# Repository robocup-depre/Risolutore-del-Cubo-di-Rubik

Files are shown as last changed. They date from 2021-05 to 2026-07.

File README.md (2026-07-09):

# Rubik's Cube Solver

An automated, hardware-accelerated Rubik's Cube solver powered by a Python computer vision pipeline and an ATmega2560 microcontroller driving a 3D-printed, 6-axis stepper motor chassis. 

The machine interfaces directly with each face of the cube via a dedicated stepper motor attached to the center caps. It executes 180° rotations, as well as 90° clockwise and counterclockwise turns.

---

# Hardware Architecture & Electronics

The `Arduino/` folder contains the C++ firmware required for the microcontroller. While an Arduino Mega was used for this build, the footprint is small enough to run on an Arduino Uno as well. The system relies on **9 logical pins**:

* **Relay Control (1 Pin):** Engages or disengages the main 12V battery line. This isolates the stepper drivers when idling to eliminate motor humming and vibration.
* **Direction Line - DIR (1 Pin):** Sets the rotational direction (clockwise/counterclockwise). This line is shared globally across all stepper drivers.
* **Step Line - STEP (1 Pin):** Sends the pulse train to drive the motor steps. This line is also shared globally.
* **Enable Lines - EN1 to EN6 (6 Pins):** Individual driver enables. Because `STEP` and `DIR` are wired in parallel to all six drivers, the firmware pulls only one `EN` line low at any given instant to ensure that exactly one target motor executes the move.

The firmware listens continuously to the serial bus for instruction sets sent by the PC. Upon receiving a move command, it instantly pulses the active motor and relays an execution feedback signal back to the Python script.

> [!IMPORTANT]
> Before flashing the firmware, review the pin configuration constants at the top of the sketch file and adjust them to match your physical hardware mapping.

---

# Software & Computer Vision Pipeline

The `Python/` directory contains four modular scripts. The execution pipeline is handled through `main.py`, which initializes a Graphical User Interface (GUI) via `tkinter`.

### 1. Optical Scanning & AprilTags
Instead of using easily skewed raw color histograms, this system tracks **AprilTags** to robustly locate and identify faces under changing lighting conditions. 
* Click the first GUI button to begin scanning. 
* Follow the orientation sequence specified in `scanning_order.gif`. 
* The script triggers an audible tone upon every successful capture, signaling you to rotate the cube to the next designated position.
* **Caution:** Maintain the exact face orientations shown in the guide; scanning a face upside-down will invalidate the internal virtual cube mapping.

### 2. Move Sequence Calculation
Once the scan concludes, a 2D projection of the cube will render on-screen for validation. If correct, clicking the second button calculates the optimized algorithm sequence. 
* *Note:* The GUI will temporarily hang/freeze during the solving computation. Do not interact with the window until it completes.

### 3. Execution
Mount the cube inside the chassis mechanism as demonstrated in `insertion.gif`. Click the final button to open the serial pipe, flashing the move sequence directly to the microcontroller array.

---

# Dependencies & Prerequisites

### 3D Printing & Assembly
* The `3D Print/` folder contains the `.stl` assets. The original chassis components were drafted in Autodesk Fusion 360 and fabricated on a Sisma Everes Uno DLP system.
* Print **9 copies of each AprilTag** provided in the `AprilTag/` directory. Glue them cleanly to their corresponding color tiles on the cube.
* Mounting the rig onto a hollow wooden base is highly recommended to cleanly route wire looms and isolate the relay.

### Core Software Requirements
| Dependency | Purpose & Notes |
| :--- | :--- |
| **Python 3.8+** | Core runtime environment. Ensure it is added to your system PATH. |
| **OpenCV** | Hardware video capture pipeline  |
| **pupil_apriltags** | Tag localization and ID extraction. Required for the computer vision tracking loop. |
| **NumPy** | Array manipulations & mapping. Handles matrix transforms of the virtual cube space. |
| **Tkinter** | Native GUI framework. Standard library component. |
| **Winsound** | Audio capture queues. Windows native. |
| **CH340/ATmega Driver** | USB-to-Serial communications bridge. Necessary if your OS fails to discover the COM port mapping. |

---

# Power Delivery Specifications

The electronics run on an isolated dual-rail configuration:
* **Logic Rail:** The Arduino board is bus-powered directly through the USB host serial cable. No external step-downs or buck converters are needed.
* **Motor Rail:** A high-discharge **12V Battery** is required to drive the stepper array. 

> [!WARNING]
> Ensure all heavy-gauge power distribution lines originating from the battery terminal are properly sized. Each active stepper motor can pull a peak current of **2A** under load.

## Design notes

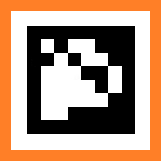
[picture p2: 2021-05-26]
Apriltags/Bordo colorato/Arancione.png

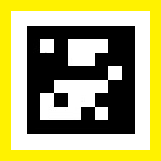
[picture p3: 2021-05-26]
Apriltags/Bordo colorato/Giallo.png

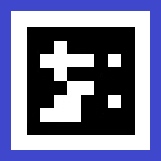
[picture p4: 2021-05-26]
Apriltags/Bordo colorato/Blu.png

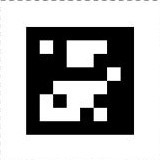
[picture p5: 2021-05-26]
Apriltags/Bianchi/Giallo.jpeg

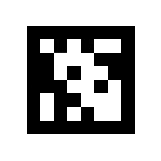
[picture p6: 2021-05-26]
Apriltags/Bordo colorato/Bianco.png

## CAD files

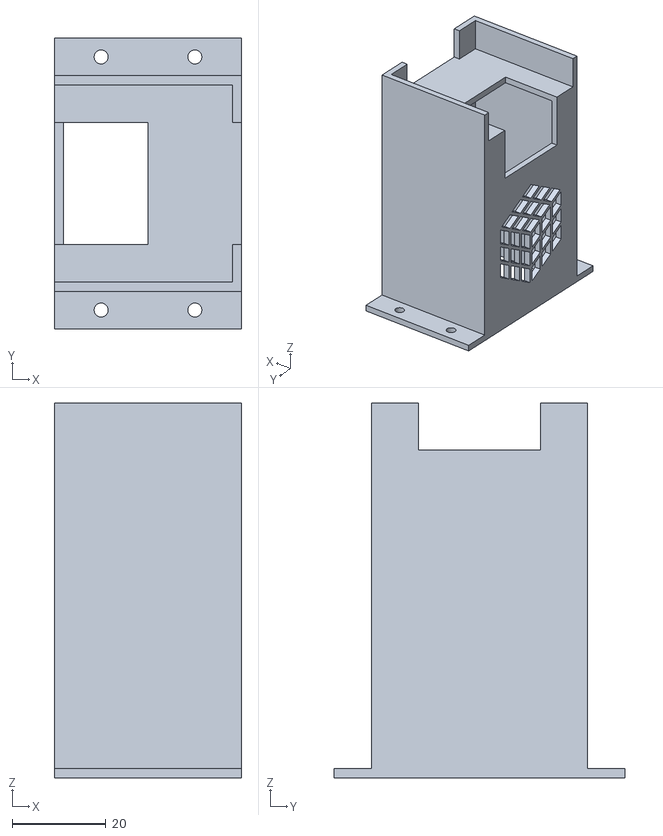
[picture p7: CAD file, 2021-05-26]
Stampa 3D/Colonna.stl
40.0 x 62.0 x 80.0

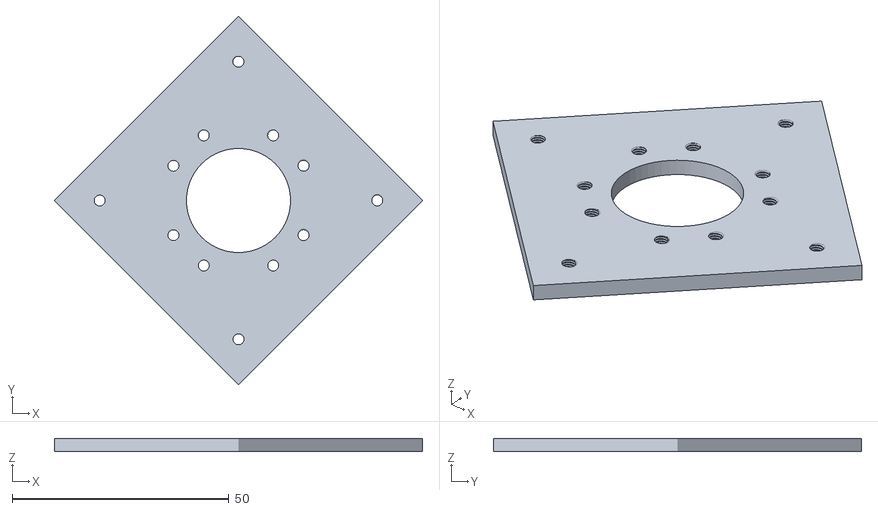
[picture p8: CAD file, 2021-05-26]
Stampa 3D/Piastra_alluminio.stl
84.9 x 84.9 x 3.00

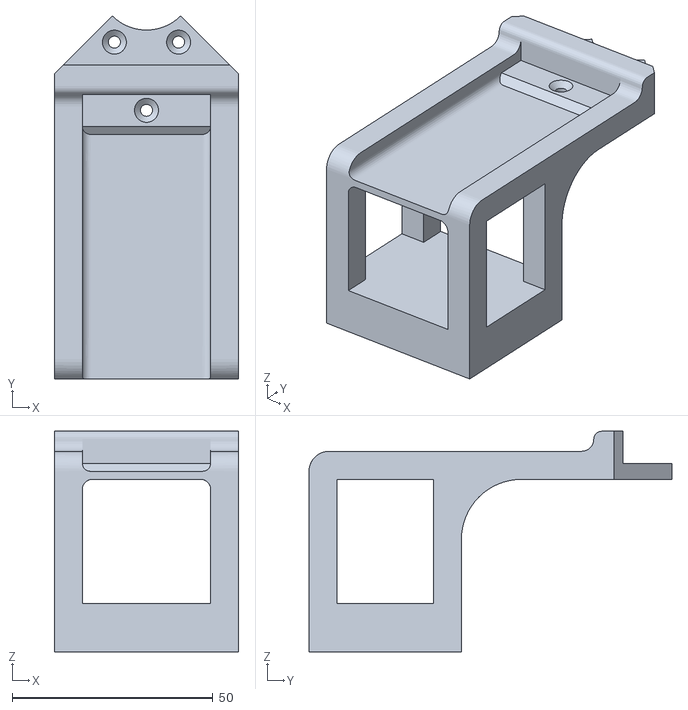
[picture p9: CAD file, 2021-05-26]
Stampa 3D/Superiore.stl
46.0 x 90.5 x 55.0

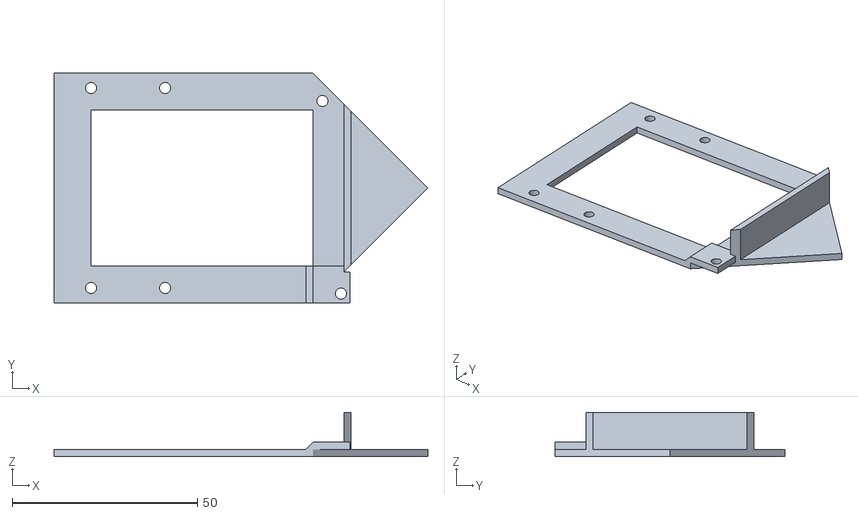
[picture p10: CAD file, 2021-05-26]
Stampa 3D/Base.stl
101.0 x 62.0 x 12.0

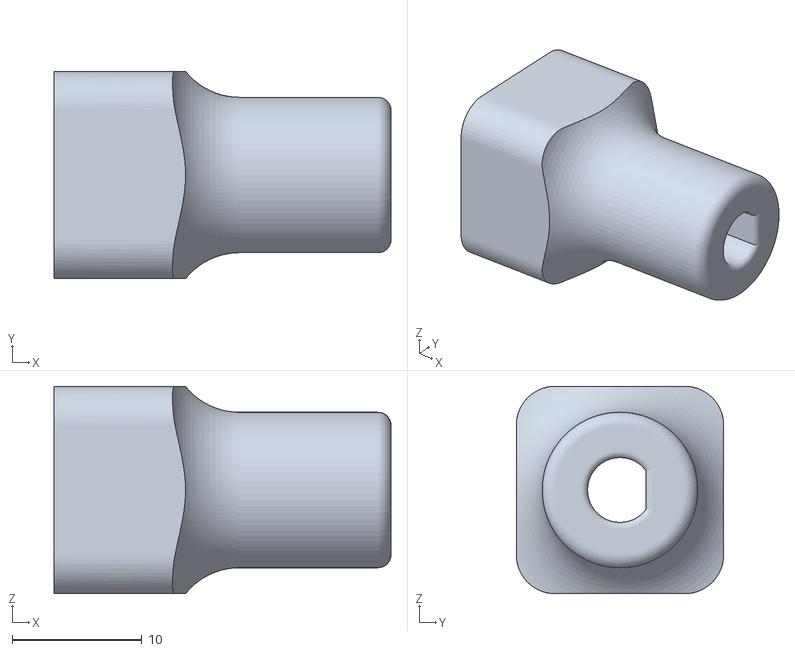
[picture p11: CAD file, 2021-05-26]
Stampa 3D/Centro.stl
26.0 x 16.0 x 16.0

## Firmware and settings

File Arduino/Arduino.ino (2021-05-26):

//HIGH significa 5V sui pin ENABLE, DIR e STEP
//LOW significa 0V sui pin ENABLE, DIR e STEP
#define u_ 20                  //definisce i pin degli enable dei driver
#define b_ 19
#define r_ 17
#define f_ 21
#define l_ 18
#define d_ 16

#define STEP 15                //definisce step e direzioni comuni
#define DIR 14

#define on LOW                 //definisce la costante on che rappresenta LOW 
                               //ovvero il driver attivo (ENABLE=0)
#define off HIGH               //definisce la costante off che rappresenta HIGH
                               //ovvero il driver disattivo (ENABLE=1)
#define orario HIGH            //definisce la costante orario che rappresenta HIGH 
                               //ovvero il verso di rotazione (DIR=1)
#define antiorario LOW         //definisce la costante antiorario che rappresenta LOW 
                               //ovvero il verso di rotazione (DIR=0)

#define tempo 1000             //pausa di 1000 micro secondi che regola la velocità durante
                               //la commutazione dello STEP da 0 a 1 e da 1 a 0 (nel ciclo for)
#define passi 50               //numero di passi nel ciclo for (corrisponde ad un angolo di 90°)
#define stabilizzazione 30     //per quanto viene tenuto fermo il motore dopo la rotazione
#define pausa 30               //pausa 30ms tra una mossa e l'altra
String input;
void setup() {
  
  Serial.begin(9600);          //Arduino trasmette dati con una velocità di 9600 bit al secondo
  for(int k=10;k<22;k++)       //imposta tutti i pin (ENABLE, STEP, DIR) come uscite e gli 
                               //assegna il valore HIGH=1 (driver disattivi)
  {
   pinMode(k,OUTPUT);          //k assume i valori dal 16 al 21, che sono i pin ENABLE, STEP e DIR
   digitalWrite(k,HIGH);
  }
  V12(on);                     //chiude il contatto del relè, così ai driver arrivano i 12V
}
void loop() 
{
  if (Serial.available()>0)
  {
    input=Serial.readStringUntil('\n');
    if (input=="Y1") 
    {
      u();
      Serial.write("u1");
    }
    if (input=="Y2") 
    {
      u2();//_________________________________________________________________
      Serial.write("u2");
    }
    if (input=="Y-1") 
    {
      u1();
      Serial.write("u-1");
    }
     if (input=="R1") 
    {
      f();
      Serial.write("f1");
    }
     if (input=="R2") 
    {
      f2();//_________________________________________________________________
      Serial.write("f2");
    }
    if (input=="R-1") 
    {
      f1();
      Serial.write("f-1");
    }
     if (input=="G1") 
    {
      r();
      Serial.write("r1");
    }
     if (input=="G2") 
    {
      r2();//_________________________________________________________________
      Serial.write("r2");
    }
     if (input=="G-1") 
    {
      r1();
      Serial.write("r-1");
    }
     if (input=="B1") 
    {
      l();
      Serial.write("l1");
    }
    if (input=="B2") 
    {
      l2();//________________________________________________________________
      Serial.write("l2");
    }
    if (input=="B-1") 
    {
      l1();
      Serial.write("l-1");
    }
     if (input=="O1") 
    {
      b();
      Serial.write("b1");
    }
    if (input=="O2") 
    {
      b2();//_______________________________________________________________
      Serial.write("b2");
    }
    if (input=="O-1") 
    {
      b1();
      Serial.write("b-1");
    }
     if (input=="W1") 
    {
      d();
      Serial.write("d1");
    }
     if (input=="W2") 
    {
      d2();
      Serial.write("d2");
    }
    if (input=="W-1") 
    {
      d1();
      Serial.write("d-1");
    }
  }
}
//____________________________________________________________________ANTIORARIO
void r1()
{
  digitalWrite(DIR,antiorario);
  digitalWrite(r_,LOW);
  for(int k=0;k<passi;k++)
  {
    digitalWrite(STEP,HIGH);
    delayMicroseconds(tempo);
    digitalWrite(STEP,LOW);
    delayMicroseconds(tempo);
  }
  delay(stabilizzazione);
  digitalWrite(r_,HIGH);
  delay(pausa);
}
void l1()
{
  digitalWrite(DIR,antiorario);
  digitalWrite(l_,LOW);
  for(int k=0;k<passi;k++)
  {
    digitalWrite(STEP,HIGH);
    delayMicroseconds(tempo);
    digitalWrite(STEP,LOW);
    delayMicroseconds(tempo);
  }
  delay(stabilizzazione);
  digitalWrite(l_,HIGH);
  delay(pausa);
}
void f1()
{
  digitalWrite(DIR,antiorario);      //assegna al pin DIR il valore antiorario (LOW, DIR=0)
  digitalWrite(f_,LOW);              //assegna al pin ENABLE del driver che comanda il 
                                     //motore Front "on" (LOW, ENABLE=0) 
  for(int k=0;k<passi;k++)           //per 50 volte alza e abbassa l'uscita del pin step 
  {
    digitalWrite(STEP,HIGH);
    delayMicroseconds(tempo);        //velocità di commutazione dello step
    digitalWrite(STEP,LOW);
    delayMicroseconds(tempo);
  }
  delay(stabilizzazione);            //l'ENABLE è ancora = 0, quindi il driver continua 
                                     //ad alimentare la stessa fase del motore 
                                     //tenendolo fermo su quel passo, 
                                     //quindi non ruota per inerzia
  digitalWrite(f_,HIGH);             //dopo che il motore è stato farmato in una posizione 
                                     //stabile disattivo il driver (ENABLE=1)
  delay(pausa);                      //fa una pausa tra una mossa e l'altra
}
void u1()
{
  digitalWrite(DIR,antiorario);
  digitalWrite(u_,LOW);
  for(int k=0;k<passi;k++)
  {
    digitalWrite(STEP,HIGH);
    delayMicroseconds(tempo);
    digitalWrite(STEP,LOW);
    delayMicroseconds(tempo);
  }
  delay(stabilizzazione);
  digitalWrite(u_,HIGH);
  delay(pausa);
}
void b1()
{
  digitalWrite(DIR,antiorario);
  digitalWrite(b_,LOW);
  for(int k=0;k<passi;k++)
  {
    digitalWrite(STEP,HIGH);
    delayMicroseconds(tempo);
    digitalWrite(STEP,LOW);
    delayMicroseconds(tempo);
  }
  delay(stabilizzazione);
  digitalWrite(b_,HIGH);
  delay(pausa);
}
void d1()
{
  digitalWrite(DIR,antiorario);
  digitalWrite(d_,LOW);
  for(int k=0;k<passi;k++)
  {
    digitalWrite(STEP,HIGH);
    delayMicroseconds(tempo);
    digitalWrite(STEP,LOW);
    delayMicroseconds(tempo);
  }
  delay(stabilizzazione);
  digitalWrite(d_,HIGH);
  delay(pausa);
}
//____________________________________________________________________________DOPPIE
void r2()
{
  digitalWrite(DIR,antiorario);
  digitalWrite(r_,LOW);
  for(int k=0;k<passi*2;k++)
  {
    digitalWrite(STEP,HIGH);
    delayMicroseconds(tempo);
    digitalWrite(STEP,LOW);
    delayMicroseconds(tempo);
  }
  delay(stabilizzazione);
  digitalWrite(r_,HIGH);
  delay(pausa);
}
void l2()
{
  digitalWrite(DIR,antiorario);
  digitalWrite(l_,LOW);
  for(int k=0;k<passi*2;k++)
  {
    digitalWrite(STEP,HIGH);
    delayMicroseconds(tempo);
    digitalWrite(STEP,LOW);
    delayMicroseconds(tempo);
  }
  delay(stabilizzazione);
  digitalWrite(l_,HIGH);
  delay(pausa);
}
void f2()
{
  digitalWrite(DIR,antiorario);
  digitalWrite(f_,LOW);
  for(int k=0;k<passi*2;k++)
  {
    digitalWrite(STEP,HIGH);
    delayMicroseconds(tempo);
    digitalWrite(STEP,LOW);
    delayMicroseconds(tempo);
  }
  delay(stabilizzazione);
  digitalWrite(f_,HIGH);
  delay(pausa);
}
void u2()
{
  digitalWrite(DIR,antiorario);
  digitalWrite(u_,LOW);
  for(int k=0;k<passi*2;k++)
  {
    digitalWrite(STEP,HIGH);
    delayMicroseconds(tempo);
    digitalWrite(STEP,LOW);
    delayMicroseconds(tempo);
  }
  delay(stabilizzazione);
  digitalWrite(u_,HIGH);
  delay(pausa);
}
void b2()
{
  digitalWrite(DIR,antiorario);
  digitalWrite(b_,LOW);
  for(int k=0;k<passi*2;k++)
  {
    digitalWrite(STEP,HIGH);
    delayMicroseconds(tempo);
    digitalWrite(STEP,LOW);
    delayMicroseconds(tempo);
  }
  delay(stabilizzazione);
  digitalWrite(b_,HIGH);
  delay(pausa);
}
void d2()
{
  digitalWrite(DIR,antiorario);
  digitalWrite(d_,LOW);
  for(int k=0;k<passi*2;k++)
  {
    digitalWrite(STEP,HIGH);
    delayMicroseconds(tempo);
    digitalWrite(STEP,LOW);
    delayMicroseconds(tempo);
  }
  delay(stabilizzazione);
  digitalWrite(d_,HIGH);
  delay(pausa);
}
//____________________________________________________________________________ORARIO
void r()
{
  digitalWrite(DIR,orario);
  digitalWrite(r_,LOW);
  for(int k=0;k<passi;k++)
  {
    digitalWrite(STEP,HIGH);
    delayMicroseconds(tempo);
    digitalWrite(STEP,LOW);
    delayMicroseconds(tempo);
  }
  delay(stabilizzazione);
  digitalWrite(r_,HIGH);
  delay(pausa);
}
void u()
{
  digitalWrite(DIR,orario);
  digitalWrite(u_,LOW);
  for(int k=0;k<passi;k++)
  {
    digitalWrite(STEP,HIGH);
    delayMicroseconds(tempo);
    digitalWrite(STEP,LOW);
    delayMicroseconds(tempo);
  }
  delay(stabilizzazione);
  digitalWrite(u_,HIGH);
  delay(pausa);
}
void b()
{
  digitalWrite(DIR,orario);
  digitalWrite(b_,LOW);
  for(int k=0;k<passi;k++)
  {
    digitalWrite(STEP,HIGH);
    delayMicroseconds(tempo);
    digitalWrite(STEP,LOW);
    delayMicroseconds(tempo);
  }
  delay(stabilizzazione);
  digitalWrite(b_,HIGH);
  delay(pausa);
}
void l()
{
  digitalWrite(DIR,orario);
  digitalWrite(l_,LOW);
  for(int k=0;k<passi;k++)
  {
    digitalWrite(STEP,HIGH);
    delayMicroseconds(tempo);
    digitalWrite(STEP,LOW);
    delayMicroseconds(tempo);
  }
  delay(stabilizzazione);
  digitalWrite(l_,HIGH);
  delay(pausa);
}
void f()
{
  digitalWrite(DIR,orario);
  digitalWrite(f_,LOW);
  for(int k=0;k<passi;k++)
  {
    digitalWrite(STEP,HIGH);
    delayMicroseconds(tempo);
    digitalWrite(STEP,LOW);
    delayMicroseconds(tempo);
  }
  delay(stabilizzazione);
  digitalWrite(f_,HIGH);
  delay(pausa);
}
void d()
{
  digitalWrite(DIR,orario);
  digitalWrite(d_,LOW);
  for(int k=0;k<passi;k++)
  {
    digitalWrite(STEP,HIGH);
    delayMicroseconds(tempo);
    digitalWrite(STEP,LOW);
    delayMicroseconds(tempo);
  }
  delay(stabilizzazione);
  digitalWrite(d_,HIGH);
  delay(pausa);
}
//____________________________________________________________________________
void V12(int stato)                   
{
  pinMode(22,OUTPUT);                   //imposta il pin che comanda il relè come uscita
  if (stato==on)                        //se voglio chiudere il contatto (accendere i 12V)
  {
    digitalWrite(22,HIGH);              //chiude il contatto al relè alimentando la bobina
  } 
  else
  {
    digitalWrite(22,LOW);
  }
}
